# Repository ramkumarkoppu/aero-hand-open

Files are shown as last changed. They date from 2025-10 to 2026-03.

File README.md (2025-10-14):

# License

- Software (firmware, SDK, and control code) is licensed under the [Apache License 2.0](https://www.apache.org/licenses/LICENSE-2.0).
- Hardware (mechanical design, CAD models, and assembly files) is licensed under the [Creative Commons Attribution-NonCommercial-ShareAlike 4.0 International License (CC BY-NC-SA 4.0)](https://creativecommons.org/licenses/by-nc-sa/4.0/).
  
© 2025 TetherIA Inc. All rights reserved.

Aero Hand Overview

Aero Hand Open is an open-source, tendon-driven robotic hand designed and developed by TetherIA. The project aims to make dexterous manipulation research more accessible by providing a fully documented, modular, and affordable platform that can be reproduced with standard 3D printing and off-the-shelf electronic components. 

Unlike many existing robotic hands that rely on expensive proprietary actuators or complex mechanical assemblies, Aero Hand Open focuses on simplicity, reliability, and transparency. Each joint is optimized for mechanical efficiency by using tendon actuation, enabling smooth and natural motion while keeping the overall design lightweight and compact. The system integrates open-source firmware (ESP32-based) and control software compatible with ROS2, allowing seamless integration into research and educational environments. 

This repository serves as a complete open hardware and software reference for developers, students, and robotics enthusiasts.

# Aero Hand Open features:
- 7 DoFs robotic hand with 5 fingers (15 joints in total)
- Tendon-driven architecture for smooth and natural motion
- Fully 3D-printed structure, modular and easy to assemble
- Lightweight design — **<400 g**
- Affordable — complete kit for **$314 USD**
- Open-source hardware and firmware
- Independent Python SDK, and compatible with ESP32 and ROS2 systems

# Overview:

Overview1

Overview1

Overview1

Overview1

Overview1

Overview1

Overview1

# Table of Contents:
- Resources
  - Bill of Materials (BOM)
  - CAD Files and 3D Models
  - Assembly Guide
  - SDK
  - Teleoperation
- Disclaimer
- Project Updates & Community
  - Updates History
  - FAQ
  - Contact

# Resources
## Bill of Materials (BOM)
The complete list of components required to build Aero Hand Open can be found here:

 👉 Aero Hand Open – Bill of Materials

This document includes all mechanical, electronic, and printed parts — such as motors, tendons, bearings, fasteners, and 3D-printed components.

Each item is listed with its part number, vendor, quantity, and estimated cost to help you easily source or substitute parts.

CAD Files and 3D Models
All CAD and 3D model files of Aero Hand Open are available in the directory.

You can find both STEP and STL files for modification and direct 3D printing.

> CAD Files Notes:
> The absolute origin of the full assembly is at the MCP joint of middle finger

For quick setup, we also provide a “One-Click Print Pack”, which contains all parts with pre-oriented build angles optimized for print strength, surface quality, and minimal support usage.

Simply load the files into your slicer and start printing — no additional rotation or manual adjustment is required.

Printing Notes:
- Suggested Printer: Bambau Lab X1C/P1S
- Recommended material: PLA (for stiffness and dimensional accuracy)
- Suggested layer height: 0.2 mm (Nozzle Diameter 0.4mm)
- Support: Autogenerate is fine
- The hand design is fully modular — individual fingers can be printed and replaced independently
- Other information can be found in Assembly Documents

An online Onshape model is also available for quick viewing and part reference:

 👉 Aero Hand Open – Onshape Document

## Assembly Guide
The step-by-step assembly instructions for Aero Hand Open are provided in the following document:

 👉 Aero Hand Open – Assembly Guide (PDF)

This guide covers the entire build process, from mounting the actuators to routing the tendons and connecting the electronics. Each finger module can be assembled independently and attached to the palm afterward, allowing easier maintenance and quick replacement.

## Software SDK
We provide basic introduction and usage here. A detailed introduction to SDK is included in the following folder.

 👉 [`sdk/README.md`](sdk/README.md)

### Installation: 
📦 Install via pip
```bash
pip install aero-hand-sdk
```
     
🧩 Install from source (editable mode)
Clone the repository to your local machine:
```bash
git clone https://github.com/TetherIA/aero-open-sdk.git
```
     
Navigate to the cloned repository directory:
```bash
cd aero-open-sdk
```

Install the package in editable mode:
```bash
pip install -e .
```

### One-Time Setup
When setting up your hand for the first time, our setup GUI helps you configure motor IDs and test motor connections.
After installation, launch the Setup GUI with:
```bash
aero-hand-gui
```

This provides an interactive interface to configure your hand.

### Sequencing Demo
The Sequencing Demo demonstrates how different finger motions can be combined into continuous, pre-defined sequences.

This script enables users to perform complex gestures — such as pinching, opening the palm, or making a peace sign — by automatically coordinating joint movements in a timed sequence.

You can find the example code in the SDK example folder. 

👉 [`sdk/examples/`](sdk/examples)

Once the SDK is installed and the serial port has been configured, you can run any of the example scripts directly using Python as follows:

```bash
python run_sequence.py
```
[🎥 Watch the demo](assets/sequence_square.mp4)

## Teleoperation
The Teleoperation Module enables real-time remote control of Aerobotic hand for intuitive grasping and manipulation experiments.

⚙️ This feature is currently WIP.

# Disclaimer
Aero Hand Open is an open-source research prototype intended for educational and experimental purposes only.

While every effort has been made to ensure build accuracy and functionality, this design has not been validated for prolonged or heavy-duty use.

Users should exercise caution when assembling, operating, or modifying this device. TetherIA Inc. and its contributors shall not be held liable for any personal injury, property damage, or other losses resulting from the use, misuse, or modification of this design. By using this project, you acknowledge and accept full responsibility for any associated risks.

Important Notes:
- 3D-printed parts may exhibit tolerance variations depending on printer and material settings.
- The tendon-driven mechanism requires regular tension adjustment to maintain consistent motion.
- Overloading the joints or applying excessive torque may cause mechanical deformation or servo damage.
- This project is provided as is, without any warranty or guarantee of fitness for a particular purpose.

We encourage the community to share improvements, feedback, and modifications through pull requests or GitHub discussions.

Your contributions will help make Aero Hand Open more reliable and versatile for the entire robotics community.

# Project Updates & Community
## Updates History
- 10/13/2025
  - Product launched on all platforms

## FAQ
Q1: Can I modify and redistribute the Aero Hand Open design?
 A: Yes, as long as it complies with the CC BY-NC-SA 4.0 license (ro Hand Open using data gloves + robotic arms or compatible robotic interfaces. It allows users to map human finger motions to the non-commercial, attribution required, share alike).

Q2: What 3D printer and material do you recommend?
A: Any FDM printer with a ≥200×200 mm bed. PLA works best for strength and dimensional accuracy.

## Contact
For questions, feedback, or collaboration inquiries, please reach out to us through the following channels:

 🛒 Shop: [Aero Hand Open – TetherIA Store](https://shop.tetheria.ai/products/aero-hand-open?variant=51112290320696) 

 📧 Email: support@tetheria.ai

 🌐 Website: [tetheria.ai](http://tetheria.ai)

 🐙 GitHub: [TetherIA](https://github.com/TetherIA)

 💬 Discord: [TetherIA Discord Channel](http://discord.gg/eRAzPMCm)

We welcome discussions, contributions, and new ideas from the community.

If you have improvements to the design, firmware, or control software, feel free to open a Pull Request or start a Discussion on GitHub.

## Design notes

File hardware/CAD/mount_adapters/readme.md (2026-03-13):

This folder contains all the adapters for Aero Hand Open designed for different robotic systems.

For instructions on connecting the adapter(s) with Aero Hand Open, please refer to [Adapter_Assembly_Instructions.pdf](Adapter_Assembly_Instructions.pdf).

## Available Adapters

**piper_arm_adapter.stp** - Designed for the [Piper Arm robotic system](https://global.agilex.ai/products/piper).

**threaded_mount_adapter.stl** - Designed to connect with a tripod mount, as demonstrated in our [previous X post](https://x.com/TetherIA_ai/status/1987711095533113664?s=20).

**135degrees_adapter.stl** - A special adapter for the Piper robot arm that provides an optimal grasping angle. See [reference image](assets/135degrees_adapter.png).

**G1_Open_Unitree_Converter.stl** - adapter for [unitree G1 robot](https://www.unitree.com/g1)

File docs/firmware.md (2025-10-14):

# Firmware

This guide covers architecture, build options, and a detailed communication protocol specification used by the **ESP32‑S3 (Seeed Studio XIAO ESP32S3)** to drive **Feetech HLS3606M servos**.

---

## 🧭 Overview

The firmware exposes a compact **fixed 16‑byte binary serial protocol** for commanding seven actuators (thumb & fingers) and for querying telemetry (position, velocity, current, temperature). It also implements **homing**, **set-id**, **persistent trims**, and safety behaviors on‑board, so a host PC can remain simple.

**Channels (7):**

1. Thumb CMC Abduction Actuator
2. Thumb CMC Flexion Actuator
3. Thumb Tendon Actuator
4. Index Finger Actuator 
5. Middle Finger Actuator
6. Ring Finger Actuator
7. Pinky Finger Actuator

---

## 🧰 Hardware & Software Requirements

* **MCU:** Seeed Studio XIAO ESP32‑S3 (8 MB flash recommended)
* **Servos:** Feetech HLS/SC family (e.g., HLS3606M), IDs mapped to 7 actuators
* **Power:** Servo rail 6–9 V with adequate current capacity; USB-C 5 V for MCU. We recommend a stable power supply at 6V for driving the hand capable of delivering upto 10A.
* **Tools:** Arduino IDE **or** PlatformIO

---

## ⚡ Quick Start

1. **Select the hand** (left/right) in `HandConfig.h` or via a build flag (see below).
2. **Build & flash:**
   * **PlatformIO:** choose `seeed_xiao_esp32s3` ➜ **Upload**
   * **Arduino IDE:** open main sketch ➜ set board to **XIAO ESP32S3** ➜ **Upload**
3. **First boot:** open a serial monitor at the configured baud (commonly 921600 or 1 000 000). Verify the board enumerates and servos respond OK if power is connected.

---

## 📁 Repository Layout

```
/firmware
  ├─ firmware_v0.1.0.ino         # Main sketch: init, parser, handlers, tasks
  ├─ HandConfig.h                # LEFT_HAND / RIGHT_HAND selection
  ├─ Homing.h                    # Homing API + ServoData type
  ├─ Homing.cpp                  # Homing implementation + baselines
  └─ libraries/                  # Third‑party libraries as needed
```

---

## 🔁 Build Configuration: Left vs Right Hand

You can switch hands either by editing `HandConfig.h` **or** using build flags.

* **PlatformIO** (`platformio.ini`):

  ```ini
  [env:seeed_xiao_esp32s3]
  platform = espressif32
  board = seeed_xiao_esp32s3
  framework = arduino
  build_flags = -DRIGHT_HAND       ; or -DLEFT_HAND
  ```
* **Arduino IDE:** temporarily uncomment the macro in `HandConfig.h`.

> Tip: Keep a default committed (often `RIGHT_HAND`) and override via CI or local flags when building the opposite hand.
> Note: You can also use the aero-hand-gui to upload a bin file directly onto the ESP32S3 without using any of this software.

---

## 🔌 Communication Protocol

The protocol is **always 16 bytes** per frame, both **to** and **from** the device. Payload words are **little‑endian**.

### Frame Format

| Bytes | Field | Description |
| ----: | --- | --- |
| 0 | **OPCODE**  | Command / request code |
| 1 | **FILLER**  | Always `0x00` (reserved) |
| 2..15 | **PAYLOAD** | 14‑byte payload; semantics depend on opcode |

> **ACK/Responses** also use the same 16‑byte frame shape; byte 0 contains the response opcode, byte 1 is `0x00`.

### Opcode Reference

> The table below is the canonical mapping used by this firmware version.

| Opcode | Name | Direction | Payload (PC→Device unless noted)  | Notes |
| :----: | --- | :---: | --- | --- |
| `0x01` | **HOMING** | PC→Dev  | none (payload = zeros) | Runs full homing & calibration; blocks other commands until complete; returns an ACK. |
| `0x02` | **SET_ID** | PC→Dev  | `u16 new_id`, `u16 current_limit` | Scans bus for the single attached servo, sets its ID and current limit; returns an ACK with old/new ID and limit. |
| `0x03` | **TRIM** | PC→Dev  | `u16 channel`, `s16 degrees_off`  | Adjusts stored **extend_count** for a channel; persists in NVS; returns an ACK with the resulting extend count. |
| `0x11` | **CTRL_POS** | PC→Dev  | 7×`u16` (ch0..ch6) | Position write for all channels. 0..65535 spans each channel’s **extend ↔ grasp**. No ACK (fire‑and‑go). |
| `0x12` | **CTRL_TOR** | PC→Dev  | TBD | Reserved/To‑be‑implemented torque/effort mode. |
| `0x22` | **GET_POS**  | PC→Dev  | none | Device replies with 7×`u16` raw positions. |
| `0x23` | **GET_VEL**  | PC→Dev  | none | Device replies with 7×`u16` velocities. |
| `0x24` | **GET_CURR** | PC→Dev  | none | Device replies with 7×`u16` currents. |
| `0x25` | **GET_TEMP** | PC→Dev  | none | Device replies with 7×`u16` temperatures. |

#### Position Mapping (CTRL_POS)

For each channel *i*, the firmware maps host value `u16[i]∈[0,65535]` linearly to the servo’s raw count using the per‑channel `extend_count` (open) and `grasp_count` (closed), clamped to `[0,4095]`. Direction is handled via `servo_direction`.

#### Example Sequences

* **Homing**
  PC → Dev: `[0x01, 0x00, 14×0x00]`
  Dev homes all servos → Dev → PC: `[0x01, 0x00, 14×0x00]`

* **Trim channel 3 by −100°**
  PC → Dev: `[0x03, 0x00, 0x03,0x00, 0x9C,0xFF, 10×0x00]`
  Dev updates extend count & saves to NVS → Dev → PC: `[0x03, 0x00, 0x03,0x00, ext_lo,ext_hi, rest 0]`

> **Framing robustness:** Unrecognized opcodes are consumed/ignored to maintain alignment; malformed frames are dropped.

---

## 🧱 Firmware Architecture

### Data Structures

```c++
struct ServoData {              // one per channel
  uint16_t grasp_count;         // closed endpoint (0..4095)
  uint16_t extend_count;        // open endpoint  (0..4095)
  int8_t   servo_direction;     // +1 or −1
};
```

* **Baselines:** compile‑time constants for LEFT and RIGHT hands (7 entries each). A runtime working copy `sd[7]` is refreshed from the baseline (e.g., at boot or before homing).

### Homing Module

* `HOMING_start()` — runs the homing routine for all servos.
* `HOMING_isBusy()` — returns `true` while homing is in progress.
* `resetSdToBaseline()` — copies the correct baseline values into `sd[7]`.

### Concurrency & I/O

* **Bus locking:** all sync read/write operations acquire a semaphore (e.g., `gBusMux`) to prevent collisions.
* **Persistence:** trims (extend counts) are stored in **NVS** so they survive reboots; a full **HOMING** reset returns to baseline.
* **Telemetry:** batched `SyncRead` used for GET_*; CSV printing (if enabled) multiplexed through a single serial writer.

---

## 🧰 Homing Behavior

1. Load the appropriate baseline via `resetSdToBaseline()`.
2. For each servo, drive slowly toward a mechanical stop while monitoring current to detect contact.
3. Calibrate the offset at contact, back‑off/settle, then move to a consistent **extend** posture.

**Notes:** Homing may take around a minute or two overall since each servo is given a timeout of 25s to find a hard mechanical stop in a given direction. During homing, other commands are ignored (buffer on the host if needed), So it will wait for an ACK for a given time period.

---

## 🧩 Extending the Firmware (Add a New Command)

Follow this pattern to add features like LED blink, torque enable, or special saves.

**Step 1 — Define a new opcode**

```c++
static const uint8_t OP_BLINK = 0x42;   // choose an unused byte
```

**Step 2 — Implement a small handler**

```c++
static void handleBlink(uint8_t count) {
  for (uint8_t i = 0; i < count; ++i) {
    digitalWrite(LED_BUILTIN, HIGH); delay(80);
    digitalWrite(LED_BUILTIN, LOW);  delay(80);
  }
}
```

**Step 3 — Wire it into the parser**

```c++
case OP_BLINK: {
  uint8_t count = payload[0];   // interpret first payload byte
  handleBlink(count);
  break;
}
```

**Step 4 — (Optional) ACK**
Return a 16‑byte response if the host should be notified of completion or status.

**Step 5 — Update host tools**
Extend your Python SDK/GUI (e.g., `aero_hand.py`) to emit and consume the new opcode.

---

## 🔐 Safety & Best Practices

* Start with conservative speeds/torque when testing.
* Ensure the servo supply can deliver peak current without large drops.
* Avoid high‑rate position writes during homing.
* Use `HOMING` to re‑establish known geometry if trims become inconsistent.
* Always check power if the servos are not moving.

---

## 🧯 Troubleshooting

* **Wrong hand geometry:** Verify build flag (`-DLEFT_HAND` vs `-DRIGHT_HAND`).
* **Servos move opposite:** Check `servo_direction` or swap extend/grasp counts. We recommend not to change the servo_direction , extend_count can be changed by Trim Servo.
* **Homing stalls:** Inspect current limits/timeouts; verify mechanics move freely.
* **No serial activity:** Confirm COM port/baud and that frames are exactly 16 bytes with valid opcodes.

---

## 📄 License

This project is licensed under **Apache License‑2.0** 

---
## 🤝 Contribution

We welcome community contributions!

If you would like to improve the [Firmware](https://github.com/TetherIA/aero-open-firmware) or add new features:

1. Fork and create a feature branch.
2. Add or modify opcodes and handlers as described in Section 9.
3. Include brief unit/bench tests where possible.
4. Commit your changes with clear messages.
5. Push your branch to your fork.
6. Open a PR with a summary and scope of changes.

---

## 🤝 Support & Contact

* Open a GitHub Issue on the project repository
* Email: **[contact@tetheria.ai](mailto:contact@tetheria.ai)**

<div align="center">
  <br/>
    <b>Happy building!</b><br/>
    Try something new, Break things safely, Share what you learn.<br/>
    If this helps, please ⭐ the repo and share it with others!<br/>
  <br/><br/>
  Built with ❤️ by TetherIA.ai
</div>

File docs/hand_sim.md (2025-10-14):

# Sim and RL

The **TetherIA Aero Hand Open** features a physically accurate **tendon-driven actuation system** that emulates real cable mechanics, allowing control and observation directly in **tendon space**. This design provides a faithful bridge between simulation and real-world deployment.

The hand can be simulated across multiple physics platforms. Currently, it supports the **[MuJoCo simulator](https://mujoco.org/)**, where it is fully integrated into **[MuJoCo Playground](https://github.com/google-deepmind/mujoco_playground)** for seamless visualization, training, and evaluation of tendon-space control policies. Support for additional simulation platforms is currently in progress.

- **Hand Model:** [MuJoCo Menagerie – TetherIA Aero Hand Open](https://github.com/TetherIA/mujoco_menagerie/tree/main/tetheria_aero_hand_open)  
- **Training Tools:** [MuJoCo Playground](https://github.com/TetherIA/mujoco_playground_pr)

---

## 🚀 Quick Start

If you’d like to **train your own policy**, follow these steps:

1. Install **MuJoCo Playground** following the [installation guide](https://github.com/TetherIA/mujoco_playground_pr/blob/main/README.md).  
2. Try the built-in **Z-axis rotation environment** for a quick demo, or create your own custom task following [this example](https://github.com/TetherIA/mujoco_playground_pr/blob/main/mujoco_playground/_src/manipulation/aero_hand/rotate_z.py).  
3. Launch training with:

```bash
python learning/train_jax_ppo.py --env_name AeroCubeRotateZAxis
```
You can replace `AeroCubeRotateZAxis` with the name of your own environment. After training, a rollout video will be saved as `rollout0.mp4`.

If you'd like to explore TetherIA Aero Hand Open within the MuJoCo simulator, follow these steps:

1. Follow the [official MuJoCo installation guide](https://mujoco.readthedocs.io/en/latest/programming/#getting-started).
2. The hand model is hosted under our fork of the MuJoCo Menagerie:
   ```bash
      git clone git@github.com:TetherIA/mujoco_menagerie.git
   ```
3. Navigate to the hand’s directory and open the simulation scene:
   ```bash
      cd mujoco_menagerie/tetheria_aero_hand_open
      simulate scene_right.xml
   ```

**Main features include:**
- Physically consistent tendon routing and pulley mechanics.  
- Full tendon-space control and observation interface.  
- JAX-based PPO training integrated with MuJoCo Playground.  

An overview of the hand is shown below:

| Rock | Paper | Scissor |
|---|---|---|

---

## 1. TetherIA Aero Hand Model

### 1.1 Modeling

The simulation model is derived from URDF models, accurately representing the real mechanical structure. The simulation reproduces the cable actuation through three essential components:

#### 1.1.1 Tendon Drives
Spatial tendons drive the fingers and thumb, following the same routing paths as the real hand.

#### 1.1.2 Springs
Modeled as tendon elements, springs generate restoring forces for finger extension, mirroring the real mechanical springs.

#### 1.1.3 Pulleys
Cylindrical pulleys guide cables and springs to ensure accurate routing and consistent actuation behavior.

| Front view | Close-up of index |
|---|---|
| skeleton | index |

---

### 1.2 Parameters

#### 1.2.1 Mechanical Parameters
- **Joint limits, mass, and inertia:** directly taken from the URDF for physical fidelity.  
- **Pulley placement:** matches the real hand’s geometry, ensuring correct cable and spring routing.  
- **Validation:** the simulated tendon range (0.0459454 m) closely matches the real hand (0.04553 m) without manual adjustment.

#### 1.2.2 Tendon and Spring Specifications
- **Tendon properties:** identical to the real system.  
- **Spring properties:** match hardware specifications, except for the DIP spring—adjusted slightly for more realistic motion.

#### 1.2.3 Control Parameters
All remaining control parameters are fine-tuned to ensure consistent dynamics between simulation and hardware, including:
- Joint damping values  
- Actuator gains  
- Joint-specific damping coefficients. 

---

## 2. Training a Tendon-Space Policy

We introduce a **Z-axis rotation task** for the **TetherIA Aero Hand Open**, optimized using the following reward function:

reward = 1.0 × angular velocity - 1.0 × action rate + termination (-100.0)

The optimization variables include **tendon lengths** and the **thumb abduction joint**, both corresponding to the real actuation system. This design ensures that the same control and sensing channels can be directly applied in **sim-to-real deployment**.

To train the policy:

```bash
python learning/train_jax_ppo.py --env_name AeroCubeRotateZAxis
```

While training results vary slightly due to stochasticity, runs consistently **converge toward a positive total reward**. Below are example reward curves obtained using PPO:

**Overall Reward**
overall

**Angular Velocity Reward**
reward_angvel

**Action-Rate Penalty**
penalty_action_rate

**Termination Penalty**
penalty_termination

---

## 3. Running a Pretrained Policy

This example builds upon **[MuJoCo Playground](https://github.com/google-deepmind/mujoco_playground)** as an educational platform. We are actively working to merge **[our implementation](https://github.com/TetherIA/mujoco_playground_pr)** into the official repository.

To test a trained policy:
```bash
python learning/train_jax_ppo.py
--env_name AeroCubeRotateZAxis
--play_only
--load_checkpoint_path path/to/checkpoints
```

This will:
- Load the trained PPO policy  
- Run rollouts in simulation  
- Visualize the manipulation behavior

| Seed 0 | Seed 1 | Seed 14 |
|---|---|---|
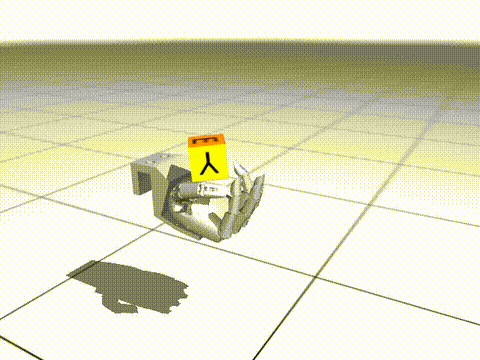
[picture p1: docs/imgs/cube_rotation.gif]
seed0
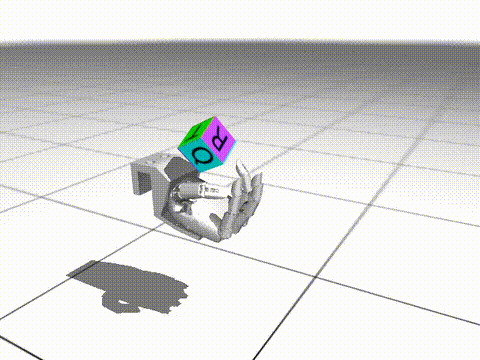
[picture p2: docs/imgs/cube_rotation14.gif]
seed14
|  | seed1 |  |

**Sim-to-Real Deployment on the TetherIA Aero Hand Open**

Z-Axis Rotation Demo

*Note: The finger markers are for visualization only and are **not** used for control.*

---

## 🧩 Acknowledgements

Dependency:  
- [**MuJoCo Playground**](https://github.com/google-deepmind/mujoco_playground).

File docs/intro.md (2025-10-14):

# Aero Hand Open

**Aero Hand Open** is a tendon-driven, under-actuated dexterous robotic hand built for research in manipulation, reinforcement learning, and embodied AI.  
It is designed for reproducibility, transparency, and ease of integration across hardware, firmware, and software layers.

---

## Hardware Overview

The hand adopts a **tendon-driven actuation architecture**, where each motor drives multiple joints through cable routing.  
This approach achieves high dexterity with fewer actuators, resulting in a lightweight and compliant design.

**Key characteristics:**
- 15 Degrees of Freedom (7 active, 8 passive)
- 3 active DoFs for the thumb, enabling real dexterity
- One-motor-per-finger tendon actuation
- Passive 1:1 coupling between DIP and PIP joints
- Adaptive coupling at MCP joint for compliant contact behavior
- Compact servo actuator modules with integrated encoders
- Modular 3D-printable mechanical components
- 6 V DC power input and USB communication
- Fully open-source CAD and PCB design

All mechanical and electrical design files are available in the [`aero-open-hardware`](https://github.com/TetherIA/aero-open-hardware) repository.

---

## Firmware and Control

The onboard controller runs custom firmware supporting:
- Position, velocity, and torque control modes
- High-frequency communication over USB
- Real-time command streaming via ROS 2 and Python SDK
- Built-in calibration and diagnostics utilities

Firmware source code is hosted in [`aero-open-firmware`](https://github.com/TetherIA/aero-open-firmware).

---

## SDK and ROS 2 Integration

Developers can interface with the hand through:
- A **Python SDK** for joint, tendon, and sensor interfaces
- **ROS 2 packages** exposing scripting, teleoperation, and logging
- Example nodes for control, data collection, and policy playback

Software API is maintained in [`aero-open-sdk`](https://github.com/TetherIA/aero-open-sdk).

---

## Simulation and Learning

Aero Hand Open is fully supported in **MuJoCo** with upcoming Issac Sim support, with tendon-level actuation and observation.  
It integrates with popular RL and imitation learning frameworks, including **MuJoCo Playground** and **LeRobot** (coming soon), enabling a consistent sim-to-real workflow.

Use simulation to train control policies, benchmark algorithms, and prototype manipulation tasks before deployment on real hardware.

---

## Repository Structure

| Component | Repository | Description |
|---|---|---|
| Hardware | [`aero-open-hardware`](https://github.com/TetherIA/aero-open-hardware) | CAD models, assembly, and tendon routing |
| Firmware | [`aero-open-firmware`](https://github.com/TetherIA/aero-open-firmware) | Embedded control software |
| SDK / GUI | [`aero-open-sdk`](https://github.com/TetherIA/aero-open-sdk) | Python SDK and GUI |
| Documentation | [`aero-open-docs`](https://github.com/TetherIA/aero-open-docs) | Documentation source |
| Monorepo | [`aero-hand-open`](https://github.com/TetherIA/aero-hand-open) | Consolidated repository for community contributions |

---

## Getting Started

- [Build and assemble the hand →](./assembly.md)  
- [Flash and verify firmware →](./firmware.md)  
- [Connect via ROS 2 or Python SDK →](./sdk.md)
- [Getting Started with GUI of SDK →](./getting_started.md)  
- [Run simulation in MuJoCo →](./hand_sim.md)

---

## License

All components of Aero Hand Open are released under permissive open-source licenses.  
Please refer to individual repositories for license details.

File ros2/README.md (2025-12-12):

<p align="center">
  Aero Hand Open by TetherIA
  <br/><br/>
</p>
 
<div align="center">




</div>

<h2 align="center">
  <p>Aero Hand ROS2 — ROS2 package for for TetherIA's Robotic Hand</p>
</h2>

<div align="center">
  Aero Hand Demo Aero Hand in action
  <p><strong>Aero Hand Open</strong> is a 7-DoF tendon-driven robotic hand for dexterous manipulation and research.</p>
</div>

---

## ⚙️ Installation

We currently have tested the ROS2 package on **Ubuntu 22.04** with **ROS2 Humble Hawksbill**.

### Prerequisites

Before installing this package, ensure you have:
- ROS2 Humble installed. Follow the official guide [here](https://docs.ros.org/en/humble/Installation/Ubuntu-Install-Debians.html).
- `colcon` build tool installed. You can install it via:
  ```bash
  sudo apt install python3-colcon-common-extensions
  ```
- The [Aero Hand SDK](https://github.com/TetherIA/aero-hand-open/tree/main/sdk) installed, follow the installation instructions in its README.

### Installation Steps

To install the `aero-open-ros2` package, follow these steps:

1. Clone the repository to your local machine:
   ```bash
   git clone https://github.com/TetherIA/aero-open-ros2.git
   ```

2. Navigate to the cloned repository directory:
   ```bash
   cd aero-open-ros2
   ```

3. Build the packages with colcon:
   ```bash
   colcon build
   ```

4. Source the workspace:
   ```bash
   source install/setup.bash
   ```

---

## 🚀 Next Steps

Take a look at the [Aero Hand Open README](src/aero_hand_open/README.md) next to get started with using the Aero Hand Open ROS2 package.

## 🧰 Troubleshooting

Coming soon — common setup and runtime issues will be documented here.

## 💬 Support

If you encounter issues or have feature requests:
- Open a [GitHub Issue](https://github.com/TetherIA/aero-open-ros2/issues)
- Contact us at **support@tetheria.ai**

---

## 🤝 Contribution

We welcome community contributions!

If you'd like to improve the SDK, fix bugs, or add new features:

1. Fork this repository.
2. Create a new branch for your changes.
    ```bash
    git checkout -b feature/your-feature-name
    ```

3. Commit your changes with clear messages.

4. Push your branch to your fork.

5. Open a Pull Request (PR) describing your updates.

---

## ⚖️ License

This project is licensed under the **Apache License 2.0**.

<div align="center">
If you find this project useful, please give it a star! ⭐

Built with ❤️ by TetherIA.ai
</div>

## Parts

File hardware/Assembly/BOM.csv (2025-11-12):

 | P/N | Name | Material | Qty per Hand | Volume (mm^3) | Total Cost per Hand | Link | Alternative | Notes
3D Printed | 1 | Finger Base | PLA | 4 | 975 | 0.024362813 | Bambu Lab |  | 3DP parts have been designed for PLA printed on a Bambu X1C with a 0.4mm nozzle. Tolerances may need to change if printing with different materials/nozzles/printers.
 | 2 | Finger MCP | PLA | 4 | 606 | 0.015142425
 | 3 | Finger Proximal | PLA | 4 | 5776 | 0.1443278
 | 4 | Finger Medial | PLA | 4 | 2644 | 0.06606695
 | 5 | Finger Distal | PLA | 4 | 1547 | 0.038655663
 | 6 | Cable Spool | PLA | 6 | 735 | 0.018365813
 | 7 | Thumb Abduction Upper Servo Disk | PLA | 1 | 786 | 0.019640175
 | 8 | Thumb Abduction Lower Servo Disk | PLA | 1 | 1366 | 0.034132925
 | 9 | Thumb Abduction Linkage Bar | PLA | 1 | 334 | 0.008345825
 | 10 | Thumb CMC Base | PLA | 1 | 5548 | 0.13863065
 | 11 | Thumb MCP | PLA | 1 | 11204 | 0.27995995
 | 12 | Thumb Proximal | PLA | 1 | 6926 | 0.173063425
 | 13 | Thumb Distal | PLA | 1 | 3912 | 0.0977511
 | 14 | Servo Frame | PLA | 1 | 15055 | 0.376186813
 | 15 | Palm Front Frame | PLA | 1 | 18734 | 0.468115825
 | 16 | Palm Rear Frame | PLA | 1 | 106254 | 2.655021825
 | 17 | Silicone molds Top | PLA | 1 | 39531 | 0.987780863
 | 18 | Silicone molds Bottom | PLA | 1 | 51643 | 1.290429463
Casting | 19 | Finger Distal Pad | 00-30 Silicone | 4 | 1322 | 0.02754653 | https://www.amazon.com/Ecoflex-00-30-Super-Platinum-Silicone/dp/B00CA5VY3U |  | We recomend using silicone pads to maximize compliance and grip however we also provide files for tpu to replace the foam. The hand functionality will be slightly lowered with the use of TPU.
 | 20 | Finger Proximal Pad | 00-31 Silicone | 4 | 1123 | 0.023399965
 | 21 | Thumb Distal Pad | 00-32 Silicone | 1 | 2998 | 0.062469363
 | 22 | Palm Frame Pad | 00-33 Silicone | 1 | 12180 | 0.253794808
 |  | Name | Material | Qty per Hand | Unit Cost | Total Cost Per Hand | Link | Alternative | Notes
Purchased Components | 23 | Finger Distal/Medial and Thumb Proximal/Distal Return Spring (PIP) | Music Wire | 5 | 5.27 | 26.35 | https://www.thespringstore.com/pe020-140-33500-mw-0840-mh-n-in.html
 | 24 | Finger Proximal/MCP Return Spring (MP) | Music Wire | 4 | 3.27 | 13.08 | https://www.centuryspring.com/shop/m-35cs
 | 25 | Thumb CMC/MCP Return Spring (CMC) | Music Wire | 1 | 4.93 | 4.93 | https://www.thespringstore.com/pe023-172-11218-mw-0470-mh-n-in.html
 | 26 | Finger Pull Cable | Kevlar/Vectran | 3 | 6.29 | 6.29 | https://www.amazon.com/9KM-DWLIFE-Strength-Retardant-Ridgeline/dp/B0B1WKH21R?s=sporting-goods | https://twinline-usa.com/collections/vectran-per-pound/products/braided-vectran-125-spools | The hand is designed to use this specific vectran however kevlar can be used
 | 27 | Pinky Pull Cable | Kevlar/Vectran | 1
 | 28 | Finger Coupling Cable | Kevlar/Vectran | 4
 | 29 | Thumb CMC Flex Cable | Kevlar/Vectran | 1
 | 30 | Thumb Pull Cable | Kevlar/Vectran | 1
 | 31 | Thumb Coupling Cable | Kevlar/Vectran | 1
 | 32 | 2x5x2.5 bearing | Steel | 23 | 0.5216 | 11.9968 | https://www.amazon.com/Yodaoke-MR52ZZ-2x5x2-5mm-Miniature-Bearings/dp/B08L7NTVK7 | https://www.amazon.com/dp/B08L7NTVK7?ref=fed_asin_title | Pins and bearings can vary depending on the supplier. The biggest issue will be fitting pins through the bearings. We recommend buying undersized pins to ensure the pins maintain a slip fit with the bearings. We spec a cheap bearing from amazon that works, however if there are fitment issues we recomend using the bearings from misumi
 | 33 | 1x10 Pin | Steel | 16 | 0.158 | 2.528 | https://www.mcmaster.com/91585A091/ | https://us.misumi-ec.com/vona2/detail/110300255260/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
 | 34 | obsolete (2x10 Pin) | Steel | 0 | 0.159 | 0 | https://www.mcmaster.com/91585A221/ | https://us.misumi-ec.com/vona2/detail/110300255260/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
 | 35 | 2x14 Pin | Steel | 12 | 0.194 | 2.328 | https://www.mcmaster.com/91585A226/ | https://us.misumi-ec.com/vona2/detail/221000746912/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
 | 36 | 2x20 Pin | Steel | 2 | 1 | 2 | https://www.mcmaster.com/91585A240/ | https://us.misumi-ec.com/vona2/detail/110300255260/?HissuCode=MSCSS2-20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
 | 37 | UNDERSIZED 2x10 Pin | Steel | 19 | 0.156 | 2.964 | https://www.mcmaster.com/97049A104/ | https://us.misumi-ec.com/vona2/detail/110302390530/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
 | 38 | UNDERSIZED 2x20 Pin | Steel | 1 | 1.52 | 1.52 | https://us.misumi-ec.com/vona2/detail/110302390530/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 | https://us.misumi-ec.com/vona2/detail/110302390530/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
 | 39 | UNDERSIZED 2x30 Pin | Steel | 1 | 1.34 | 1.34 | https://us.misumi-ec.com/vona2/detail/110302390530/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 | https://us.misumi-ec.com/vona2/detail/110302390530/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
 | 40 | M2x6 Flanged Torx Self Tapping Screw | Steel | 25 | 0.403 | 10.075 | https://www.mcmaster.com/catalog/131/3434/96817A406
 | 41 | M2x10 Countersunk Torx Self Tapping Screw | Steel | 12 | 0.3 | 3.6 | https://www.mcmaster.com/95893A167/
 | 42 | M3x10 Rounded Torx Self Tapping Screw | Steel | 9 | 0.118 | 1.062 | https://www.mcmaster.com/96817A322/
 | 43 | M3x5.7 Heat set insert | Brass | 4 | 0.209 | 0.836 | https://www.mcmaster.com/94459A140/
 | 44 | Feetech HLS3606M Servo Motor | Comes with purchase of servo from Feetech | 7 | 29.83 | 208.81 | https://www.alibaba.com/product-detail/FEETECH-HLS3606M-6V-6Kg-cm-Torque_1601281149843.html
 | 45 | Servo Motor Mount Plate
 | 46 | Servo Motor Spline Screw M2.3x5
 | 47 | Servo Motor Plate Screw M2x4
 | 48 | Connection Board and Cable
 | 49 | TTLinker Mini UART Signal Conversion Board | PCB | 1 | 1.58 | 1.58 | https://www.alibaba.com/product-detail/TTLinker-Mini-UART-Signal-Conversion-Board_60370504430.html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
 | 50 | ESP32-S3 | PCB | 1 | 7.99 | 7.99 | https://www.seeedstudio.com/XIAO-ESP32S3-p-5627.html
 |  | Total |  |  |  | 316.482991
Optional |  | Molex Connector | - | 7 | 0.21 | 1.47 | https://www.digikey.com/en/products/detail/molex/0022035035/403302 |  | For optional soldered breadboard or you can use the Feetech junction boards that come with each servo to daisy chain the servos together and control them or you can buy/make the pcb design we are working on
 |  | Proto Board | - | 1 | 13.5 | 13.5 | https://www.sparkfun.com/sparkfun-snappable-protoboard.html

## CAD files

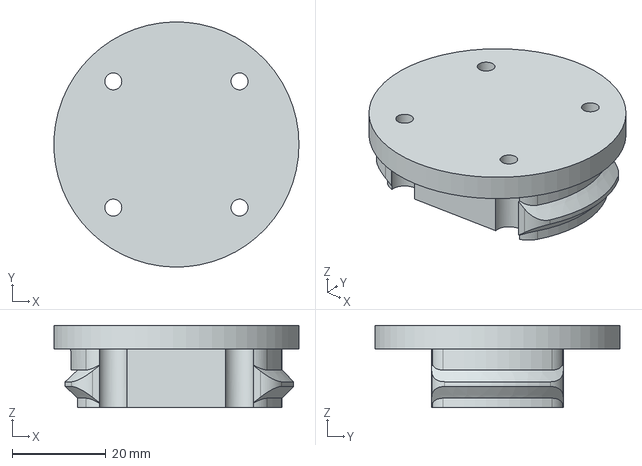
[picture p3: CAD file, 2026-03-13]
hardware/CAD/mount_adapters/G1_Open_Unitree_Converter.stp
52.2 x 52.2 x 17.5 mm

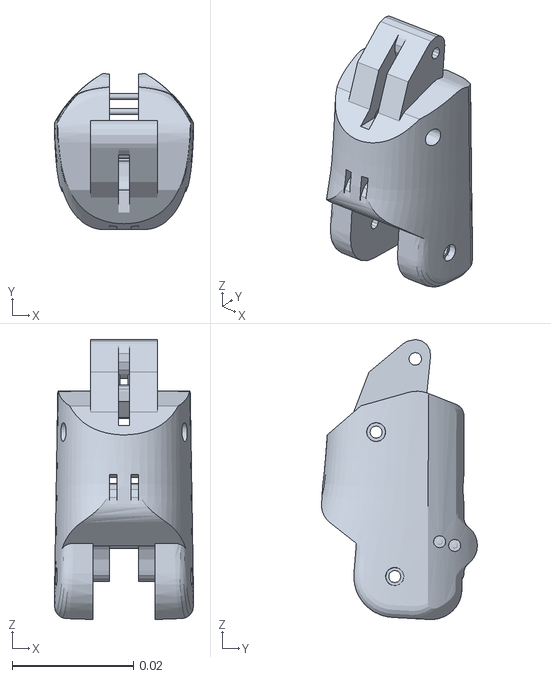
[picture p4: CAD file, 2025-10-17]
ros2/src/aero_hand_open_description/meshes/right_thumb_mcp_link.STL
0.023 x 0.0257 x 0.0461

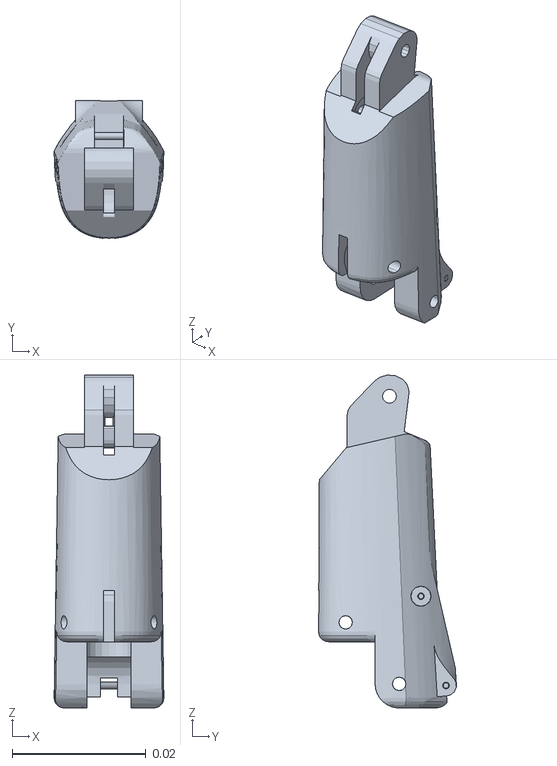
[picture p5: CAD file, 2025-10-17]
ros2/src/aero_hand_open_description/meshes/right_middle_proximal_link.STL
0.0164 x 0.0206 x 0.0498

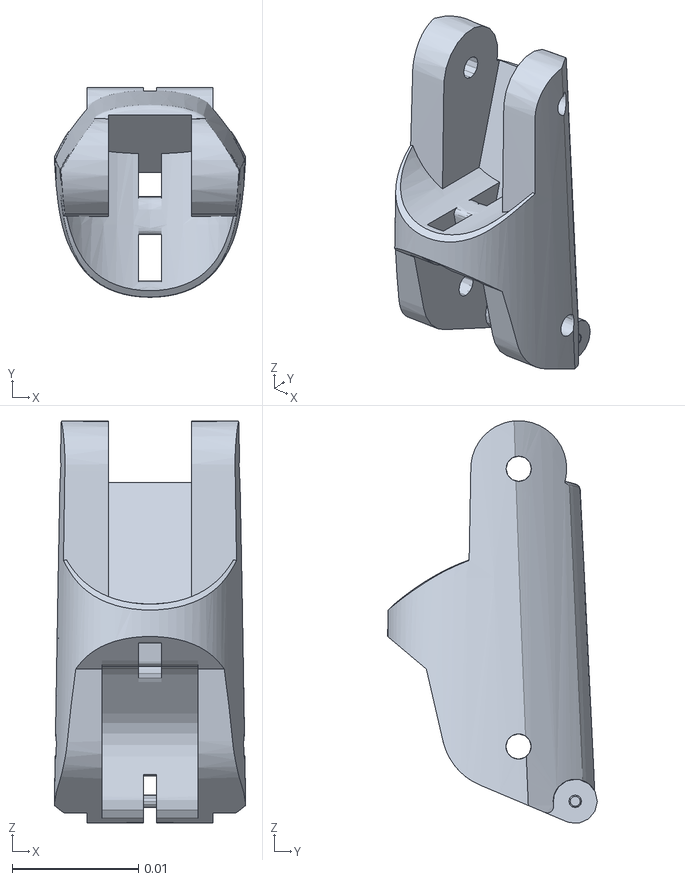
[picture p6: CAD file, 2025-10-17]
ros2/src/aero_hand_open_description/meshes/right_pinky_middle_link.STL
0.0152 x 0.0166 x 0.0318

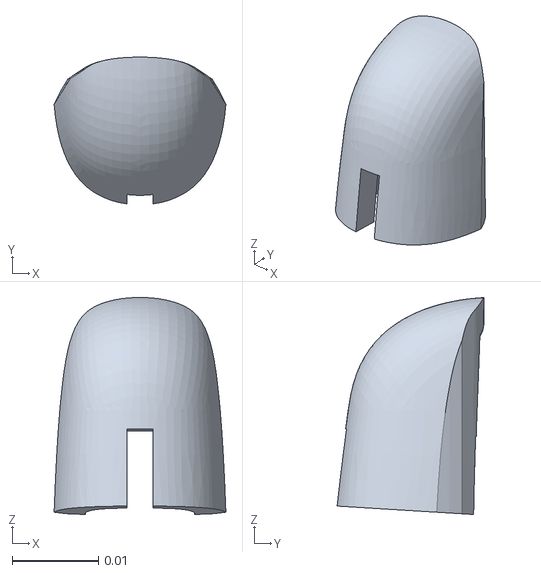
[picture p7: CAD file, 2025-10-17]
ros2/src/aero_hand_open_description/meshes/right_thumb_tip_link.STL
0.0199 x 0.017 x 0.0251

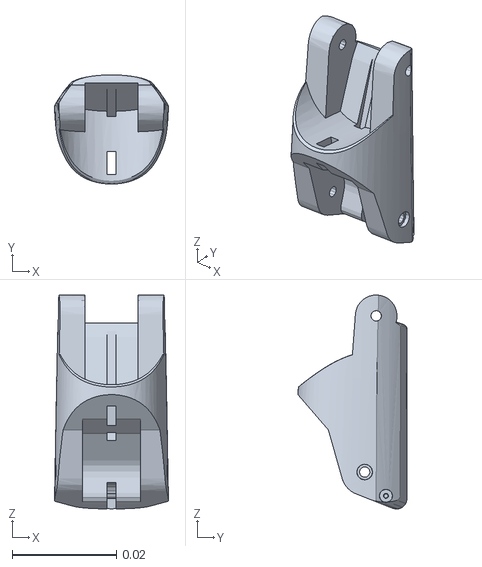
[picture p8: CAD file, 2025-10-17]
ros2/src/aero_hand_open_description/meshes/right_thumb_proximal_link.STL
0.0218 x 0.0209 x 0.041

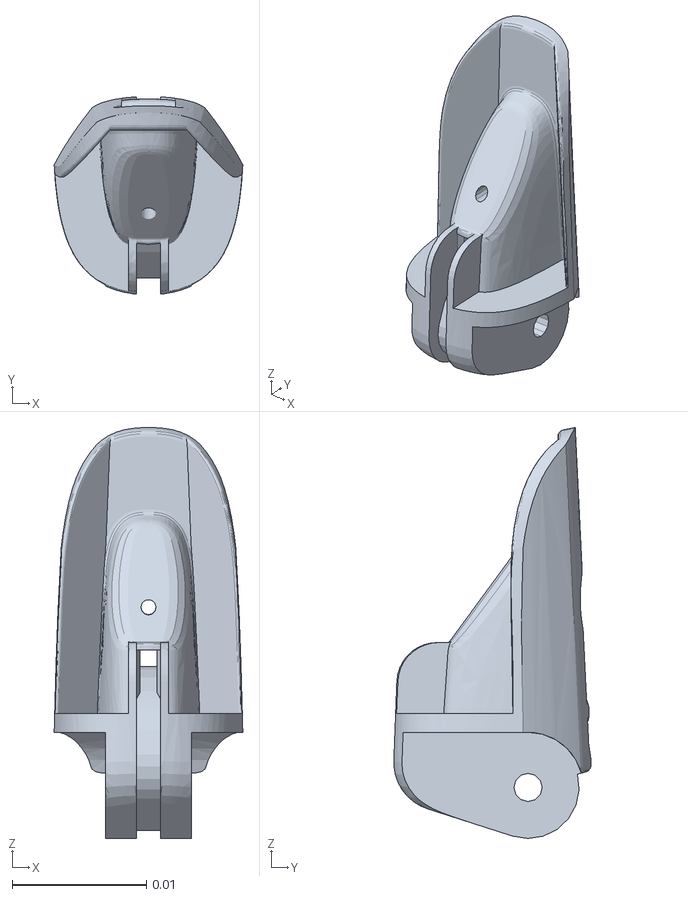
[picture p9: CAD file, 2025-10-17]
ros2/src/aero_hand_open_description/meshes/right_ring_distal_link.STL
0.014 x 0.0147 x 0.0306

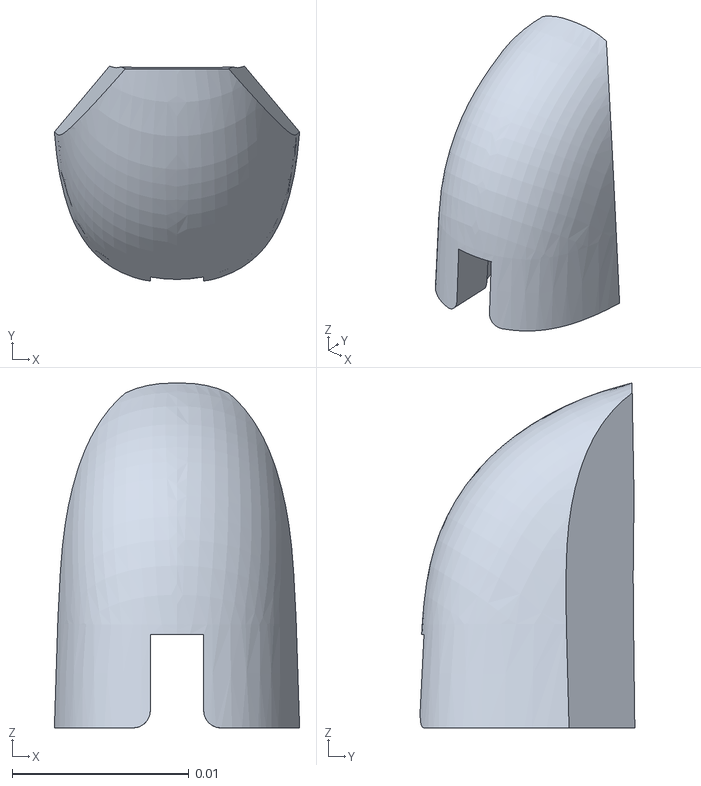
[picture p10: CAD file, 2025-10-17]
ros2/src/aero_hand_open_description/meshes/right_pinky_tip_link.STL
0.0139 x 0.0121 x 0.0195

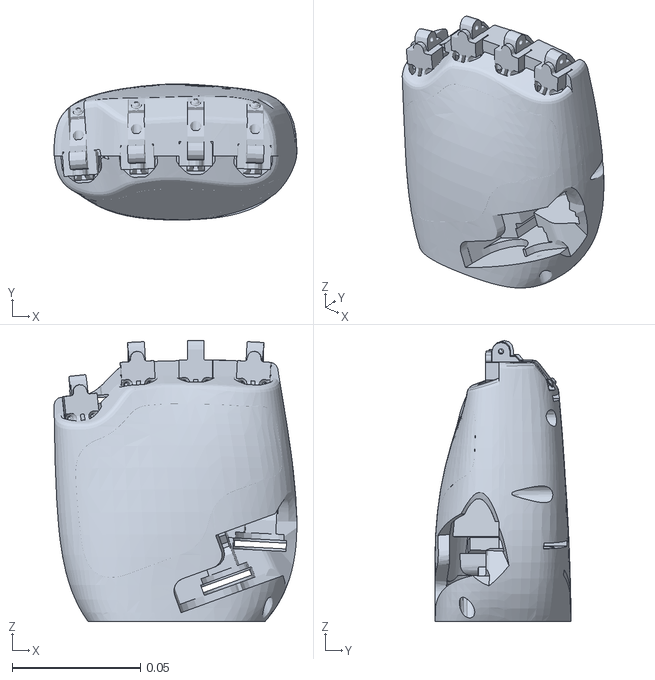
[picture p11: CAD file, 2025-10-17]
ros2/src/aero_hand_open_description/meshes/right_base_link.STL
0.0946 x 0.053 x 0.109

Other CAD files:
ros2/src/aero_hand_open_description/meshes/right_index_proximal_link.STL
ros2/src/aero_hand_open_description/meshes/right_index_middle_link.STL
ros2/src/aero_hand_open_description/meshes/right_pinky_distal_link.STL
ros2/src/aero_hand_open_description/meshes/right_index_tip_link.STL
ros2/src/aero_hand_open_description/meshes/right_ring_tip_link.STL
ros2/src/aero_hand_open_description/meshes/right_ring_middle_link.STL
ros2/src/aero_hand_open_description/meshes/right_middle_middle_link.STL
ros2/src/aero_hand_open_description/meshes/right_middle_tip_link.STL
ros2/src/aero_hand_open_description/meshes/right_middle_distal_link.STL
ros2/src/aero_hand_open_description/meshes/right_index_distal_link.STL
ros2/src/aero_hand_open_description/meshes/right_pinky_proximal_link.STL
ros2/src/aero_hand_open_description/meshes/right_ring_proximal_link.STL
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

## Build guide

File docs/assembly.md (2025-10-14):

# Assembly Instructions

This page contains the complete assembly instructions for the Aero Hand.

## View Instructions

You can view the assembly instructions PDF below, or [download it directly](./Assembly_Instructions.pdf).

<div style={{position: 'relative', width: '100%', height: '800px', border: '1px solid #ccc', borderRadius: '4px', overflow: 'hidden'}}>
  <iframe
    src={require('./Assembly_Instructions.pdf').default}
    style={{width: '100%', height: '100%', border: 'none'}}
    title="Assembly Instructions PDF"
  />
</div>

## Download

If the embedded viewer doesn't work in your browser, you can [download the PDF file here](./Assembly_Instructions.pdf).

---

:::tip
If you have any questions during assembly, please reach out to our community on [Discord](https://discord.gg/eRAzPMCm).
:::

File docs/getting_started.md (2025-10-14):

# First - Time Setup
## 🖥️ GUI — Aero Hand Open Control App

Launch the GUI from a terminal after installation:

```bash
aero-hand-gui
```

> If your system can’t find the command, ensure your Python environment’s scripts directory is on PATH and that the package was installed into the active environment.

<div align="center">
  Screenshot of GUI
</div>

### 🧩 First‑Time Setup: Uploading Firmware

To upload firmware to your Aero Hand device:

1. **Refresh all ports** in the GUI to detect connected devices.
2. If multiple ports are listed, identify the port for your ESP device:
  - On **Windows**, it is usually a **COM** port (e.g., COM3, COM12).
  - On **Linux**, look for `/dev/ttyACM0`, `/dev/ttyACM1`, etc.
3. Select the correct port and press the **Upload Firmware** button.
4. A dialog box will open—navigate to and select the appropriate firmware `.bin` file (`firmware_righthand.bin` or `firmware_lefthand.bin`).
5. The tool will upload the `.bin` file to the device at offset address **0x10000**.
6. On successful upload, you will see a confirmation message in the GUI.

uploading Firmware

#### Notes & Troubleshooting

1. If you encounter errors, first check that you have selected the correct COM port.
2. The tool uses **esptool version 5 or greater**. Older versions may not work, as they use `write_flash` instead of `write-flash`.
3. After flashing, the tool will attempt to reconnect to the ESP automatically (up to 3 attempts). Usually, it connects on the first try. If not, refresh your ports and try again.
4. The firmware is uploaded to offset **0x10000**. Do not use merged or partition `.bin` files, as these may cause errors. Only use the provided bin files from the `aero-open-firmware` repository.

Next step is to set the servo IDs, see the next section below.

### Setting Servo -IDs

1. **Power** the board with the 6V and connect USB.
2. **Connect exactly one servo** to the bus.
3. In the GUI, choose the correct **COM Port**, press **Connect**.
4. Click **Set ID** and assign the servo for the channel you’re wiring:
  * `0 → thumb_abduction_actuator`
  * `1 → thumb_flex_actuator`
  * `2 → thumb_tendon_actuator`
  * `3 → index_finger_actuator`
  * `4 → middle_finger_actuator`
  * `5 → ring_finger_actuator`
  * `6 → pinky_finger_actuator`
5. If the id is successfully set, You will receive an ACK in the RX bar below.
6. If you receive 65535 in oldid,new id and current as ACK , It indicates that the id is not successfully set.
7. After setting up the ID, you can move the responsible slider to make sure whether the actuator is moving or not.
8. Disconnect that servo, plug the next one, and **repeat** until all seven are assigned.

Setting Servo - IDs

### Notes & Troubleshooting

1. Make sure that the board has power and exactly one servo is connected before setting the ID.
2. We recommend setting IDs for all servos in sequence (0–6). Any value apart from 0–6 will not be accepted.
3. For current limit, we recommend keeping it at the maximum (1023) and pressing OK—do not change this value unless necessary.
4. After setting the ID, you will receive the old ID, new ID, and current limit of the servo as confirmation.
5. If you receive 65535 in old ID, new ID, and current limit, this indicates that two or more servos are present and the Set ID mode will not proceed.
6. Once all IDs are Set, We recommend not to use this function once you are playing and training with the hand.

### Trim Servo

When using Trim Servo:
First, you will be asked to enter the servo channel (0–6), which represents the sequence: thumb abduction, thumb flexion, thumb tendon, and the four fingers. Next, enter the degrees offset. We recommend making adjustments in steps of 10–20 degrees, then observe the effect using the sliders. If something unusual happens, you may need to perform the homing procedure again to reset the extend count to the baseline.

#### Left Hand Actuator Table
| Channel | Actuator Name | Extend Count | Grasp Count | Motion (°) | Direction | 
|---|---|---|---|---|---|
| 0 | Thumb Abduction | 2048 | 3186 | 100 | +1 | 
| 1 | Thumb Flexion | 865 | 2048 | 104 | -1 | 
| 2 | Thumb Tendon | 2980 | 0 | 262 | +1 | 
| 3 | Index Finger | 817 | 4095 | 288 | -1 | 
| 4 | Middle Finger | 817 | 4095 | 288 | -1 | 
| 5 | Ring Finger | 817 | 4095 | 288 | -1 |
| 6 | Pinky Finger | 817 | 4095 | 288 | -1 |

#### Right Hand Actuator Table

| Channel | Actuator Name | Extend Count | Grasp Count | Motion (°) | Direction | 
|---|---|---|---|---|---|
| 0 | Thumb Abduction | 2048 | 910 | 100 | -1 |
| 1 | Thumb Flexion | 3231 | 2048 | 104 | +1 |
| 2 | Thumb Tendon | 1115 | 4095 | 262 | -1 | 
| 3 | Index Finger | 3278 | 0 | 288 | +1 | 
| 4 | Middle Finger | 3278 | 0 | 288 | +1 |
| 5 | Ring Finger | 3278 | 0 | 288 | +1 |
| 6 | Pinky Finger | 3278 | 0 | 288 | +1 |

*Motion (°) is calculated as (Grasp Count - Extend Count) / 11.375*

##### Example: Trimming Right Hand Servo Channel 2 by +10 Degrees

Suppose you set +10 degrees trim for the right hand, servo channel 2 (Thumb Tendon Actuator):
- Original Extend Count: 1115
- Grasp Count: 4095
- Each degree corresponds to 11.375 counts.
- So, +10 degrees will update Extend Count to:
  
  1115 + (10 × 11.375) = 1228 (rounded to 1228)

- The new range of motion will be:
  
  4095 - 1228 = 2867 counts

This means the servo will now move through 2867 counts instead of the original 2980 counts which represent 262 degrees of motion and now it will move 252 degrees of total motion only, which will reduce the full range of motion and make it more tight. If you do in the opposite direction , It will increase the motion of servo which will loose the wire and may cause issues. Since , You cannot mofidy the grasp count of the servo, We recommned to go through this table before doing any changes.

Trim Servo

#### Notes & Troubleshooting
1. Do not enter values like 360 or -360 degrees, as this may completely change your control direction—please avoid this.
2. If the servo becomes too tight, try loosening it by entering degrees in the opposite direction to your last adjustment.
3. Use this function only when you want fine control over the servo's range of motion.
4. Disconnect power immediately if any actuator moves to an abrupt position and draws stall current (typically 1.3–1.5A).

### 🎛️ Top Bar Controls

* **Port**: Dropdown of available serial ports.
  Use **Refresh** to re‑scan if you plug/unplug devices.
* **Baud**: Serial speed. Default 921600 is typical for fast streaming and our firmware uses the same baudrate as well.
* **Connect / Disconnect**: Open or close the selected serial port.
* **Rate (Hz)**: How often the GUI streams **CTRL_POS** frames while you move sliders.
  **Recommended:** 50 Hz for smooth motion without saturating USB.

### 🧪 Action Buttons (left→right)

* **Homing** 🏠: Sends opcode `0x01` to run the on‑board homing routine.Any Other Input is ignored while homing is active; wait for ACK under a given timeout of 3minutes.
* **Set ID** 🆔: Guided flow to set a servo’s bus ID. Requires a **single** servo connected; the firmware verifies this before writing.
* **Trim Servo** ✂️: Fine‑tune alignment per channel. Enter **channel (0–6)** and **degrees offset** (±). The firmware adjusts/persists the channel’s `extend_count` in NVS so it survives reboots. Use small steps (±5–10°) and test.
* **Upload Firmware** ⬆️: Flash a `.bin` directly from the GUI. After selection, the board is reset into bootloader, the image is written, and the device restarts.
* **Set to Extend** 🔄: Sends a single **CTRL_POS** frame that sets **all channels to 0.000** (fully open / extend posture). Handy as a “panic open”.
* **GET_POS** 📍: Requests positions. Values are shown normalized **0.000 → 1.000**, computed from each channel’s `extend↔grasp` calibration (host 0..65535).
* **GET_VEL** 💨: Requests velocities of the actuator motions.
* **GET_CURR** 🔌: Requests currents in **mA**, **signed** — the **sign reflects motor direction** relative to the channel’s servo direction (use magnitude to gauge load).
* **GET_TEMP** 🌡️: Requests temperatures (°C) from each servo.
* **GET_ALL** 📦: Convenience burst that triggers **POS + VEL + CURR + TEMP** reads in one go and prints results to the log.

### 🧷 Sliders Panel (Center)

Each row controls a single actuator channel with a **normalized slider**:

* **0.000 → 1.000** maps linearly to the channel’s calibrated **extend ↔ grasp** range in 2 bytes and sent as 14 bytes payload using CTRL_POS Command.
* While you drag, the GUI streams **CTRL_POS** frames at the selected **Rate (Hz)**.
* Two small numeric readouts show the current command and (when polled) the latest normalized feedback.

**Channel map (top→bottom):** `thumb_abduction_actuator`, `thumb_flex_actuator`, `thumb_tendon_actuator`, `index_finger_actuator`, `middle_finger_actuator`, `ring_finger_actuator`, `pinky_finger_actuator`.

### 📟 Status & Logs (Bottom)

* **Status bar** (left): Connection state (e.g., *Disconnected*, *COM12 @ 921600*), last error, and homing/flash progress messages.
* **RX Log**: Text console of responses/telemetry. Useful for debugging, verifying opcodes, and viewing GET_* results.
* **Clear Log**: Clears the RX Log display (does not affect device state).

### 🧰 Tips & Tricks

* **Port not listed?** Click **Refresh**; check drivers, cables, and that no other app is holding the port.
* **Set‑ID fails?** Ensure only one servo is connected and the servo rail is powered.
* **No motion?** Verify you selected the correct hand build (left/right), try **Set to Extend**, then move sliders slowly.
* **Choppy control?** Lower **Rate (Hz)** or close other serial/USB‑heavy apps.

### 🐍 Python Control & Examples

Prefer scripting or automation? Use the Python SDK to send the same 16‑byte frames programmatically and log telemetry.

* Import the high‑level class (e.g., `AeroHand`) and browse **examples** in this repo’s `examples/` folder.
* The GUI and SDK speak the **same protocol**, so your scripts and the app can be used interchangeably during development.

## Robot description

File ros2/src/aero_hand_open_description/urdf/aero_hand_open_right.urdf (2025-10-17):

<?xml version="1.0" encoding="utf-8"?>
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
<robot name="aero_hand_open_right">
  <link name="right_base_link">
    <inertial>
      <origin xyz="0.00109122507694746 0.00334946623951281 0.0489855934276007" rpy="0 0 0" />
      <mass value="0.303576106034272" />
      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
    </inertial>
    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
  </link>
  <link name="right_t_link">
    <inertial>
      <origin xyz="-0.000883525104759189 0.00170407980029484 0.00831028240403424" rpy="0 0 0" />
      <mass value="0.00833536405562315" />
      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
    </inertial>
    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
  </link>
  <joint name="right_thumb_cmc_abd" type="revolute">
    <origin xyz="0.028112 -0.0145 0.025363" rpy="-1.2217 -0.0 -1.57" />
    <parent link="right_base_link" />
    <child link="right_t_link" />
    <axis xyz="0 1 0" />
    <limit lower="0" upper="1.7453" effort="0" velocity="0" />
  </joint>
  <link name="right_thumb_mcp_link">
    <inertial>
      <origin xyz="-1.9848E-07 0.00075445 0.014668" rpy="0 0 0" />
      <mass value="0.008207" />
      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
    </inertial>
    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
  </link>
  <joint name="right_thumb_cmc_flex" type="revolute">
    <origin xyz="-0.003475 0.003808 0.019656" rpy="0.1325 -0.17906 0.26195" />
    <parent link="right_t_link" />
    <child link="right_thumb_mcp_link" />
    <axis xyz="1 0 0" />
    <limit lower="0" upper="0.9599" effort="0" velocity="0" />
  </joint>
  <link name="right_thumb_proximal_link">
    <inertial>
      <origin xyz="7.9121E-09 0.001007 0.011955" rpy="0 0 0" />
      <mass value="0.005471" />
      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
    </inertial>
    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
  </link>
  <joint name="right_thumb_mcp" type="revolute">
    <origin xyz="0 0.0033822 0.035848" rpy="0 0 0" />
    <parent link="right_thumb_mcp_link" />
    <child link="right_thumb_proximal_link" />
    <axis xyz="1 0 0" />
    <limit lower="0" upper="1.5708" effort="0" velocity="0" />
  </joint>
  <link name="right_thumb_distal_link">
    <inertial>
      <origin xyz="-6.4155E-07 -0.0011983 0.010377" rpy="0 0 0" />
      <mass value="0.0032396" />
      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
    </inertial>
    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
  </link>
  <joint name="right_thumb_ip" type="revolute">
    <origin xyz="0 0.002206 0.029919" rpy="0 0 0" />
    <parent link="right_thumb_proximal_link" />
    <child link="right_thumb_distal_link" />
    <axis xyz="1 0 0" />
    <limit lower="0" upper="1.5708" effort="0" velocity="0" />
  </joint>
  <link name="right_thumb_tip_link">
    <inertial>
      <origin xyz="2.2383E-07 -0.010203 -0.013939" rpy="0 0 0" />
      <mass value="0.00086967" />
      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
    </inertial>
    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
  </link>
  <joint name="right_thumb_tip" type="fixed">
    <origin xyz="0 0.0059474 0.031823" rpy="0 0 0" />
    <parent link="right_thumb_distal_link" />
    <child link="right_thumb_tip_link" />
    <axis xyz="0 0 0" />
  </joint>
  <link name="right_index_proximal_link">
    <inertial>
      <origin xyz="4.30529992941076E-08 -0.0024559603959039 0.0191142514901699" rpy="0 0 0" />
      <mass value="0.00720026836301954" />
      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
    </inertial>
    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
  </link>
  <joint name="right_index_mcp_flex" type="revolute">
    <origin xyz="0.030626 -0.0011782 0.10542" rpy="0 0.05236 -0.034907" />
    <parent link="right_base_link" />
    <child link="right_index_proximal_link" />
    <axis xyz="1 0 0" />
    <limit lower="0" upper="1.5708" effort="0" velocity="0" />
  </joint>
  <link name="right_index_middle_link">
    <inertial>
      <origin xyz="-6.47985752902369E-09 -0.000363269614703799 0.00876079008757696" rpy="0 0 0" />
      <mass value="0.00276150356687874" />
      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
    </inertial>
    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
  </link>
  <joint name="right_index_pip" type="revolute">
    <origin xyz="0 -0.0014554 0.043" rpy="0 0 0" />
    <parent link="right_index_proximal_link" />
    <child link="right_index_middle_link" />
    <axis xyz="1 0 0" />
    <limit lower="0" upper="1.5708" effort="0" velocity="0" />
  </joint>
  <link name="right_index_distal_link">
    <inertial>
      <origin xyz="3.34671961321059E-07 -0.00120224143694181 0.00777234707760652" rpy="0 0 0" />
      <mass value="0.00183663667769987" />
      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
    </inertial>
    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
  </link>
  <joint name="right_index_dip" type="revolute">
    <origin xyz="0 0 0.022" rpy="0 0 0" />
    <parent link="right_index_middle_link" />
    <child link="right_index_distal_link" />
    <axis xyz="1 0 0" />
    <limit lower="0" upper="1.5708" effort="0" velocity="0" />
  </joint>
  <link name="right_index_tip_link">
    <inertial>
      <origin xyz="2.3798090519056E-08 -0.00705353273135757 -0.0124434081224676" rpy="0 0 0" />
      <mass value="0.000390243409160287" />
      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
    </inertial>
    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
  </link>
  <joint name="right_index_tip" type="fixed">
    <origin xyz="0 0.003512 0.026776" rpy="0 0 0" />
    <parent link="right_index_distal_link" />
    <child link="right_index_tip_link" />
    <axis xyz="0 0 0" />
  </joint>
  <link name="right_middle_proximal_link">
    <inertial>
      <origin xyz="3.04863738940235E-08 -0.00245596411252013 0.0191142544123753" rpy="0 0 0" />
      <mass value="0.0072002618370038" />
      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
    </inertial>
    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
  </link>
  <joint name="right_middle_mcp_flex" type="revolute">
    <origin xyz="0.0075 0 0.106" rpy="0 0 0" />
    <parent link="right_base_link" />
    <child link="right_middle_proximal_link" />
    <axis xyz="1 0 0" />
    <limit lower="0" upper="1.5708" effort="0" velocity="0" />
  </joint>
  <link name="right_middle_middle_link">
    <inertial>
      <origin xyz="-2.85973601964011E-09 -0.000363264332488778 0.00876078146450842" rpy="0 0 0" />
      <mass value="0.00276150069139886" />
      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
    </inertial>
    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
  </link>
  <joint name="right_middle_pip" type="revolute">
    <origin xyz="0 -0.0014554 0.043" rpy="0 0 0" />
    <parent link="right_middle_proximal_link" />
    <child link="right_middle_middle_link" />
    <axis xyz="1 0 0" />
    <limit lower="0" upper="1.5708" effort="0" velocity="0" />
  </joint>
  <link name="right_middle_distal_link">
    <inertial>
      <origin xyz="1.25205983373364E-07 -0.00120223641223895 0.00777324919661349" rpy="0 0 0" />
      <mass value="0.00183690507488675" />
      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
    </inertial>
    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
  </link>
  <joint name="right_middle_dip" type="revolute">
    <origin xyz="0 0 0.022" rpy="0 0 0" />
    <parent link="right_middle_middle_link" />
    <child link="right_middle_distal_link" />
    <axis xyz="1 0 0" />
    <limit lower="0" upper="1.5708" effort="0" velocity="0" />
  </joint>
  <link name="right_middle_tip_link">
    <inertial>
      <origin xyz="-7.96462318148356E-08 -0.00705328274533182 -0.0124432893968912" rpy="0 0 0" />
      <mass value="0.00039026895252879" />
      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
    </inertial>
    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
  </link>
  <joint name="right_middle_tip" type="fixed">
    <origin xyz="0 0.003512 0.026776" rpy="0 0 0" />
    <parent link="right_middle_distal_link" />
    <child link="right_middle_tip_link" />
    <axis xyz="0 0 0" />
  </joint>
  <link name="right_ring_proximal_link">
    <inertial>
      <origin xyz="-2.24219388229863E-08 -0.00245596869794189 0.0191142172606163" rpy="0 0 0" />
      <mass value="0.00720026581090036" />
      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
    </inertial>
    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
  </link>
  <joint name="right_ring_mcp_flex" type="revolute">
    <origin xyz="-0.015626 -0.0011782 0.10542" rpy="0 -0.05236 0.034907" />
    <parent link="right_base_link" />
    <child link="right_ring_proximal_link" />
    <axis xyz="1 0 0" />
    <limit lower="0" upper="1.5708" effort="0" velocity="0" />
  </joint>
  <link name="right_ring_middle_link">
    <inertial>
      <origin xyz="-1.05768104170789E-08 -0.000363267692106015 0.00876078358138278" rpy="0 0 0" />
      <mass value="0.00276150640462905" />
      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
    </inertial>
    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
  </link>
  <joint name="right_ring_pip" type="revolute">
    <origin xyz="0 -0.0014554 0.043" rpy="0 0 0" />
    <parent link="right_ring_proximal_link" />
    <child link="right_ring_middle_link" />
    <axis xyz="1 0 0" />
    <limit lower="0" upper="1.5708" effort="0" velocity="0" />
  </joint>
  <link name="right_ring_distal_link">
    <inertial>
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

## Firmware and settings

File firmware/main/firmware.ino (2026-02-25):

// TetherIA - Open Source Hand
// Aero Hand Firmware Source Code
#include <Arduino.h>
#include <Wire.h>
#include <HLSCL.h>
#include <Preferences.h>
#include "HandConfig.h"
#include "Homing.h"
#include "esp_system.h"

HLSCL hlscl;
Preferences prefs;

// ---- UART pins to the servo bus (ESP32-S3 XIAO: RX=2, TX=3) ----
#define SERIAL2_TX_PIN 3
#define SERIAL2_RX_PIN 2

// ---- Servo IDs (declare at top) ----
const uint8_t SERVO_IDS[7] = { 0, 1, 2, 3, 4, 5, 6 };

ServoData sd[7];

// ---- Constants for Control Code byte ----
static const uint8_t HOMING    = 0x01;
static const uint8_t SET_ID    = 0x02;
static const uint8_t TRIM      = 0x03;
static const uint8_t CTRL_POS  = 0x11;
static const uint8_t CTRL_TOR  = 0x12;
static const uint8_t GET_POS   = 0x22;
static const uint8_t GET_VEL   = 0x23;
static const uint8_t GET_CURR  = 0x24;
static const uint8_t GET_TEMP  = 0x25;
static const uint8_t SET_SPE   = 0x31;
static const uint8_t SET_TOR   = 0x32;

// ---- Defaults for SyncWritePosEx ----
static uint16_t g_speed[7]  = {32766,32766,32766,32766,32766,32766,32766};
static uint8_t  g_accel[7]  = {0,0,0,0,0,0,0};     // 0..255
static uint16_t g_torque[7] = {700,700,700,700,700,700,700}; // 0....1000
static const uint16_t HOLD_MAG = 5;       // the minimal torque actually commanded to the motors during the torque mode. Any torque below that will not be used.

// Last commanded torque per servo (signed)
static int16_t g_lastTorqueCmd[7] = {0};

// ---- Thermal torque limiting (GLOBAL PARAMETERS) ----
static uint8_t  TEMP_CUTOFF_C    = 70;    // °C cutoff
static uint16_t HOT_TORQUE_LIMIT = 500;   // clamp torque when motor exceeds TEMP_CUTOFF_C 

// ----- Registers / constants (Mapped as per Feetech Servo HLS3606M) -----
#define REG_ID                 0x05       // ID register
#define REG_CURRENT_LIMIT      28         // decimal address (word)
#define BROADCAST_ID           0xFE
#define SCAN_MIN               0
#define SCAN_MAX               253
#define REG_BLOCK_LEN          15
#define REG_BLOCK_START        56

// ----- Structure for the Metrics of Servo -------
struct ServoMetrics {
  uint16_t pos[7];
  uint16_t vel[7];
  uint16_t cur[7];
  uint16_t tmp[7];
};
static ServoMetrics gMetrics;

// -------- Global Control Mode State  ---------
enum ControlMode{
  MODE_POS=0,
  MODE_TORQUE=2
};
static ControlMode g_currentMode = MODE_POS;

// ----- Semaphores for Metrics and Bus for acquiring lock and release it -----
static SemaphoreHandle_t gMetricsMux;
SemaphoreHandle_t gBusMux = nullptr;

// ----- Homing module API Calls (provided below as .h/.cpp) --------
bool HOMING_isBusy();
void HOMING_start();

// ---- Helper function to read latest temp from servo
static inline uint8_t getTempC(uint8_t ch) {
  uint8_t t = 0;
  if (gMetricsMux) xSemaphoreTake(gMetricsMux, portMAX_DELAY);
  t = (uint8_t)gMetrics.tmp[ch];
  if (gMetricsMux) xSemaphoreGive(gMetricsMux);
  return t;
}

static inline bool isHot(uint8_t ch) {
  return getTempC(ch) >= TEMP_CUTOFF_C;
}

static inline uint16_t u16_min(uint16_t a, uint16_t b) { return (a < b) ? a : b; }

// ---- Set-ID helpers for setting ID ---
extern void runReIdScanAndSet(uint8_t Id, uint16_t currentLimit);
static volatile int g_lastFoundId; 

// ----- Helper Functions for Set-ID Mode -----
static bool scanRequireSingleServo(uint8_t* outId, uint8_t requestedNewId) {
  uint8_t first = 0xFF;
  int count = 0;
  if (gBusMux) xSemaphoreTake(gBusMux, portMAX_DELAY);
  for (int id = SCAN_MIN; id <= SCAN_MAX; ++id) {
    if (id == BROADCAST_ID) continue;        
    (void)hlscl.Ping((uint8_t)id);
    if (!hlscl.getLastError()) {
      if (count == 0) first = (uint8_t)id;
      ++count;
      if (count > 1) break;                    
    }
  }
  if (gBusMux) xSemaphoreGive(gBusMux);
  if (count == 1) {
    if (outId) *outId = first;
    return true;
  }
  if (count == 0) {
    uint8_t ack6[6] = { 0xFF, 0x00, requestedNewId, 0x00, 0x00, 0x00 };
    sendAckFrame(SET_ID, ack6, sizeof(ack6));
    return false;
  }
  uint8_t ack14[14] = {0xFF, 0xFF, 0xFF, 0xFF, 0xFF, 0xFF, 0xFF, 0xFF, 0x00, 0x00, 0x00, 0x00, 0x00, 0x00};
  sendAckFrame(SET_ID, ack14, sizeof(ack14));
  return false;
}
static void sendSetIdAck(uint8_t oldId, uint8_t newId, uint16_t curLimitWord) {
  uint16_t vals[7] = {0};
  vals[0] = oldId;
  vals[1] = newId;
  vals[2] = curLimitWord;
  uint8_t out[2 + 7*2];
  out[0] = SET_ID;  // 0x03
  out[1] = 0x00;    // filler
  for (int i = 0; i < 7; ++i) {
    out[2 + 2*i + 0] = (uint8_t)(vals[i] & 0xFF);
    out[2 + 2*i + 1] = (uint8_t)((vals[i] >> 8) & 0xFF);
  }
  Serial.write(out, sizeof(out));
}
// ---- Helper function to save and loadManual extends from NVS ------
static void loadManualExtendsFromNVS() {
  prefs.begin("hand", true);  // read-only
  for (uint8_t i = 0; i < 7; ++i) {
    // Store extends per logical channel index, not servo bus ID.
    String key = "ext" + String(i);
    int v = prefs.getInt(key.c_str(), -1);
    if (v >= 0 && v <= 4095) {
      sd[i].extend_count = v;
    }
  }
}

static void saveExtendsToNVS() {
  prefs.begin("hand", false);  // RW
  for (uint8_t i = 0; i < 7; ++i) {
    // Store extends per logical channel index, not servo bus ID.
    String kext = "ext" + String(i);
    prefs.putInt(kext.c_str(), (int)sd[i].extend_count);
  }
  prefs.end();
}

// -------- Soft-Limit Safety for Servo motors
static void checkAndEnforceSoftLimits()
{
  static bool torqueLimited[7] = {false};
  static uint32_t lastCheckMs = 0;
  uint32_t now = millis();
  if (now - lastCheckMs < 20) return;
  lastCheckMs = now;

  if (g_currentMode != MODE_TORQUE) {
    // Only apply soft limits during torque control.
    for (int i = 0; i < 7; ++i) torqueLimited[i] = false;
    return;
  }

  if (gBusMux) xSemaphoreTake(gBusMux, portMAX_DELAY);
  for (uint8_t i = 0; i < 7; ++i) {
    uint8_t id = SERVO_IDS[i];
    int pos = hlscl.ReadPos(id);
    if (pos < 0) pos += 32768;
    uint16_t raw = pos % 4096;
    uint16_t ext = sd[i].extend_count;
    uint16_t gra = sd[i].grasp_count;
    uint16_t rawMin = min(ext, gra);
    uint16_t rawMax = max(ext, gra);
    bool inRange = (raw >= rawMin && raw <= rawMax);
    if (!inRange && !torqueLimited[i]) {
      int16_t limitedTorque = (g_lastTorqueCmd[i] >= 0) ? 200 : -200;
      hlscl.WriteEle(id, limitedTorque);
      torqueLimited[i] = true;
    } else if (inRange && torqueLimited[i]) {
      hlscl.WriteEle(id, g_lastTorqueCmd[i]);
      torqueLimited[i] = false;
    }
  }
  if (gBusMux) xSemaphoreGive(gBusMux);
}


// ---- Helper function  for raw to U16 and U16 to raw ----
static inline uint16_t mapRawToU16(uint8_t ch, uint16_t raw) {
  int32_t ext  = sd[ch].extend_count;
  int32_t gra  = sd[ch].grasp_count;
  int32_t span = gra - ext;
  if (span == 0) return 0;  // avoid divide-by-zero
  int32_t val = ((int32_t)(raw - ext) * 65535L) / span;
  //Clamp
  if (val < 0) val = 0;
  if (val > 65535) val = 65535;
  return (uint16_t)val;
}
static inline uint16_t mapU16ToRaw(uint8_t ch, uint16_t u16) {
  int32_t ext = sd[ch].extend_count;
  int32_t gra = sd[ch].grasp_count;
  int32_t raw32;
  if (ext == 0 && gra == 0) {
    raw32 = ((uint64_t)u16 * 4095u) / 65535u;
  } else {
    raw32 = ext + ((int64_t)u16 * (gra - ext)) / 65535LL;
  }
  // clamp
  if (raw32 < 0)    raw32 = 0;
  if (raw32 > 4095) raw32 = 4095;
  return (uint16_t)raw32;
}

// ---- Helper Functions for u16, Decode to sign and copy values in u16 format----
static inline uint16_t leu_u16(const uint8_t *p) {
  return (uint16_t)p[0] | ((uint16_t)p[1] << 8);
}
static inline int16_t decode_signmag15(uint8_t lo, uint8_t hi) {
  uint16_t mag = ((uint16_t)(hi & 0x7F) << 8) | lo;  // 15-bit magnitude
  return (hi & 0x80) ? -(int16_t)mag : (int16_t)mag;
}
static inline void copy7_u16(uint16_t dst[7], const uint16_t src[7]) {
  for (int i = 0; i < 7; ++i) dst[i] = src[i];
}

// ----- Helper function to send u16 frame for POS,SPD,VEL,CURR and sendACK Packet ----
static inline void sendU16Frame(uint8_t header, const uint16_t data[7]) {
  uint8_t out[2 + 7*2];
  out[0] = header;
  out[1] = 0x00; // filler
  for (int i = 0; i < 7; ++i) {
    out[2 + 2*i + 0] = (uint8_t)(data[i] & 0xFF);
    out[2 + 2*i + 1] = (uint8_t)((data[i] >> 8) & 0xFF);
  }
  Serial.write(out, sizeof(out)); 
}
static inline void sendAckFrame(uint8_t header, const uint8_t* payload, size_t n) {
  uint8_t out[16];
  out[0] = header;
  out[1] = 0x00; // filler
  memset(out + 2, 0, 14);
  if (payload && n) {
    if (n > 14) n = 14;
    memcpy(out + 2, payload, n);
  }
  Serial.write(out, sizeof(out));
}

// ----- Functions to Send POS, VEL, CURR, TEMP -----
void sendPositions() {
  uint16_t buf[7];
  xSemaphoreTake(gMetricsMux, portMAX_DELAY);
  copy7_u16(buf, gMetrics.pos);
  xSemaphoreGive(gMetricsMux);
  sendU16Frame(GET_POS, buf);
}
void sendVelocities() {
  uint16_t buf[7];
  xSemaphoreTake(gMetricsMux, portMAX_DELAY);
  copy7_u16(buf, gMetrics.vel);
  xSemaphoreGive(gMetricsMux);
  sendU16Frame(GET_VEL, buf);
}
void sendCurrents() {
  uint16_t buf[7];
  xSemaphoreTake(gMetricsMux, portMAX_DELAY);
  copy7_u16(buf, gMetrics.cur);
  xSemaphoreGive(gMetricsMux);
  sendU16Frame(GET_CURR, buf);
}
void sendTemps() {
  uint16_t buf[7];
  xSemaphoreTake(gMetricsMux, portMAX_DELAY);
  copy7_u16(buf, gMetrics.tmp);
  xSemaphoreGive(gMetricsMux);
  sendU16Frame(GET_TEMP, buf);
}

// ----- Task - Sync Read running always on Core 1 ----- 
static void TaskSyncRead_Core1(void *arg) {
  uint8_t  rx[REG_BLOCK_LEN];          // 15 bytes
  uint16_t pos[7], vel[7], cur[7], tmp[7];
  const TickType_t period = pdMS_TO_TICKS(10);   // Change Frequency of Running here, 5 -200 Hz, 10-100 Hz, 20 -50 Hz
  TickType_t nextWake = xTaskGetTickCount();
  for (;;) {
    // try-lock: if control is using the bus, skip this cycle
    if (gBusMux && xSemaphoreTake(gBusMux, 0) != pdTRUE) {
      vTaskDelayUntil(&nextWake, period);
      continue;
    }
    bool ok = true;
    // one TX for the whole group (15-byte slice)
    hlscl.syncReadPacketTx((uint8_t*)SERVO_IDS, 7, REG_BLOCK_START, REG_BLOCK_LEN);
    for (uint8_t i = 0; i < 7; ++i) {
      if (!hlscl.syncReadPacketRx(SERVO_IDS[i], rx)) { ok = false; break; }
      uint16_t raw = leu_u16(&rx[0]);
      pos[i] = mapRawToU16(i,raw);                     // Position (unsigned)
      vel[i] = decode_signmag15(rx[2], rx[3]);                  // velocity (signed)
      tmp[i] = rx[7];                                           // temperature (unsigned, 1 byte)
      cur[i] = decode_signmag15(rx[13], rx[14]);                // current (signed)
      //vTaskDelay(1);
    }
    if (gBusMux) xSemaphoreGive(gBusMux);
    if (ok) {
      xSemaphoreTake(gMetricsMux, portMAX_DELAY);
      for (int i = 0; i < 7; ++i) {
        gMetrics.pos[i] = pos[i];
        gMetrics.vel[i] = vel[i];
        gMetrics.tmp[i] = tmp[i];
        gMetrics.cur[i] = cur[i];
      }
      xSemaphoreGive(gMetricsMux);
    } 
    vTaskDelayUntil(&nextWake, period);
  }
}
//Set-ID and Trim Servo functions
static bool handleSetIdCmd(const uint8_t* payload) {
  // Parse request: two u16 words, little-endian
  uint16_t w0 = (uint16_t)payload[0] | ((uint16_t)payload[1] << 8); // newId in low byte
  uint16_t w1 = (uint16_t)payload[2] | ((uint16_t)payload[3] << 8); // requested current limit
  uint8_t  newId    = (uint8_t)(w0 & 0xFF);
  uint16_t reqLimit = (w1 > 1023) ? 1023 : w1;
  // Invalid newId → ACK with oldId=0xFF, newId, cur=0
  if (newId > 253 || newId ==BROADCAST_ID) {
    uint8_t ack[6] = { 0xFF, 0x00, newId, 0x00, 0x00, 0x00 };
    sendAckFrame(SET_ID, ack, sizeof(ack));
    return true;
  }
  // Find any servo present
  uint8_t oldId = 0xFF;
  if (!scanRequireSingleServo(&oldId, newId)) return true; 
  
  if (newId != oldId) {
  if (gBusMux) xSemaphoreTake(gBusMux, portMAX_DELAY);
  (void)hlscl.Ping(newId);
  bool taken = !hlscl.getLastError();
  if (gBusMux) xSemaphoreGive(gBusMux);
  if (taken) {
    uint8_t ack14[14] = { oldId, 0x00, newId, 0x00, 0x00, 0x00, 0x00, 0x00, 0x00, 0x00, 0x00, 0x00, 0x00, 0x00};
    sendAckFrame(SET_ID, ack14, sizeof(ack14));
    return true;
  }
  }
  if (gBusMux) xSemaphoreTake(gBusMux, portMAX_DELAY);
  (void)hlscl.unLockEprom(oldId);
  (void)hlscl.writeWord(oldId, REG_CURRENT_LIMIT, reqLimit);
  uint8_t targetId = oldId;
  if (newId != oldId) {
    (void)hlscl.writeByte(oldId, REG_ID, newId);   // REG_ID = 0x05
    targetId = newId;
  }
  (void)hlscl.LockEprom(targetId);
  
  // Read back limit for ACK
  uint16_t curLimitRead = 0;
  int rd = hlscl.readWord(targetId, REG_CURRENT_LIMIT);
  if (rd >= 0) curLimitRead = (uint16_t)rd;
  if (gBusMux) xSemaphoreGive(gBusMux);
  // Build 6-byte payload: oldId(LE16), newId(LE16), curLimit(LE16) and send
  uint8_t ack[6];
  ack[0] = oldId;                      // oldId lo
  ack[1] = 0x00;                       // oldId hi
  ack[2] = targetId;                   // newId lo
  ack[3] = 0x00;                       // newId hi
  ack[4] = (uint8_t)(curLimitRead & 0xFF);
  ack[5] = (uint8_t)((curLimitRead >> 8) & 0xFF);
  sendAckFrame(SET_ID, ack, sizeof(ack));
  return true;
}
static bool handleTrimCmd(const uint8_t* payload) {
  // Parse little-endian fields
  uint16_t rawCh  = (uint16_t)payload[0] | ((uint16_t)payload[1] << 8);
  uint16_t rawDeg = (uint16_t)payload[2] | ((uint16_t)payload[3] << 8);
  int      ch      = (int)rawCh;         // 0..6
  int16_t  degrees = (int16_t)rawDeg;    // signed degrees
  // Validate channel (0..6)
  if (ch < 0 || ch >= 7) {
    // Optionally send a NACK or silent-accept to preserve framing
    return true;
  }
  // Degrees -> counts (≈11.375 counts/deg), clamp to 0..4095
  int delta_counts = (int)((float)degrees * 11.375f);
  int new_ext = (int)sd[ch].extend_count + delta_counts;
  if (new_ext < 0)    new_ext = 0;
  if (new_ext > 4095) new_ext = 4095;
  sd[ch].extend_count = (uint16_t)new_ext;
  // Persist to NVS
  prefs.begin("hand", false);
  prefs.putInt(String("ext" + String(ch)).c_str(), sd[ch].extend_count);
  prefs.end();
  // ACK payload: ch (u16, LE), extend_count (u16, LE)
  uint8_t ack[4];
  ack[0] = (uint8_t)(ch & 0xFF);
  ack[1] = (uint8_t)((ch >> 8) & 0xFF);
  ack[2] = (uint8_t)(sd[ch].extend_count & 0xFF);
  ack[3] = (uint8_t)((sd[ch].extend_count >> 8) & 0xFF);
  sendAckFrame(TRIM, ack, sizeof(ack));   // 16 bytes on the wire
  return true;
}
static bool handleSetSpeedCmd(const uint8_t* payload)
{
  uint16_t rawId = (uint16_t)payload[0] | ((uint16_t)payload[1] << 8);
  uint16_t rawSpd = (uint16_t)payload[2] | ((uint16_t)payload[3] << 8);
  if (rawId >= 7) {
    //invalid index of servo actuator - So give error code (0–6 valid)
    uint8_t ack[4] = {0xFF, 0xFF, 0x00, 0x00};
    sendAckFrame(SET_SPE, ack, sizeof(ack));
    return true;
  }
  if (rawSpd > 32766) rawSpd = 32766;  // clamp
  g_speed[rawId] = rawSpd;
  // ACK back: servo id and speed
  uint8_t ack[4];
  ack[0] = (uint8_t)(rawId & 0xFF);
  ack[1] = (uint8_t)((rawId >> 8) & 0xFF);
  ack[2] = (uint8_t)(rawSpd & 0xFF);
  ack[3] = (uint8_t)((rawSpd >> 8) & 0xFF);
  sendAckFrame(SET_SPE, ack, sizeof(ack));
  return true;
}
static bool handleSetTorCmd(const uint8_t* payload)
{
  uint16_t rawId = (uint16_t)payload[0] | ((uint16_t)payload[1] << 8);
  uint16_t rawTor = (uint16_t)payload[2] | ((uint16_t)payload[3] << 8);
  // Validate ID range (0..6)
  if (rawId >= 7) {
    uint8_t ack[4] = {0xFF, 0xFF, 0x00, 0x00};  // invalid ID ack
    sendAckFrame(SET_TOR, ack, sizeof(ack));
    return true;
  }
  if (rawTor > 1023) rawTor = 1023;
  // Update the per-servo torque value
  g_torque[rawId] = rawTor;
  uint8_t ack[4];
  ack[0] = (uint8_t)(rawId & 0xFF);
  ack[1] = (uint8_t)((rawId >> 8) & 0xFF);
  ack[2] = (uint8_t)(rawTor & 0xFF);
  ack[3] = (uint8_t)((rawTor >> 8) & 0xFF);
  sendAckFrame(SET_TOR, ack, sizeof(ack));
  return true;
}

// ----- Returns true if a valid 16-byte frame was consumed and handled -----
static bool handleHostFrame(uint8_t op) {
  // Wait until full frame is buffered: filler + 14 payload
  while (Serial.available() < 15) { /* wait */ }
  uint8_t buf[15];
  for (int i = 0; i < 15; ++i) {
    int ch = Serial.read(); if (ch < 0) return false;
    buf[i] = (uint8_t)ch;
  }
  const uint8_t* payload = &buf[1]; // buf[0] = filler 0x00 (ignored)

  switch (op) {
    case CTRL_POS: {
      int16_t pos[7];
      for (int i = 0; i < 7; ++i) {
        uint16_t u16 = (uint16_t)payload[2*i] | ((uint16_t)payload[2*i+1] << 8);
        uint8_t  ch  = i;
        pos[i] = mapU16ToRaw(ch, u16);
      }

      // Torque Servo limit - If motor crosses the TEMP_CUTOFF_C, then keep HOT_TORQUE_LIMIT as the torque
      uint16_t torque_eff[7];
      for (int i = 0; i < 7; ++i) {
        uint16_t base = g_torque[i]; // 0..1023
        if (isHot((uint8_t)i)) {
          base = u16_min(base, HOT_TORQUE_LIMIT);
        }
        torque_eff[i] = base;
      }

      if (gBusMux) xSemaphoreTake(gBusMux, portMAX_DELAY);
      if (g_currentMode != MODE_POS) {
        for (int i = 0; i < 7; ++i) {
          uint8_t id = SERVO_IDS[i];
          hlscl.ServoMode(id);
        }
        g_currentMode = MODE_POS;
      }
      hlscl.SyncWritePosEx((uint8_t*)SERVO_IDS, 7, pos, g_speed, g_accel, torque_eff);
      if (gBusMux) xSemaphoreGive(gBusMux);
      return true;
    }

    case CTRL_TOR: 
    {   
      int16_t torque_cmd[7]; 
      for (int i = 0; i < 7; ++i) 
      {
        uint16_t mag = (uint16_t)payload[2*i] | ((uint16_t)payload[2*i + 1] << 8); 
        if (mag > 1000) mag = 1000; 
        if (mag < HOLD_MAG) mag = HOLD_MAG;
        if (isHot((uint8_t)i)) {
          mag = u16_min(mag, HOT_TORQUE_LIMIT);
        }
        int grasp_sign = (sd[i].extend_count > sd[i].grasp_count) ? +1 : -1;
        torque_cmd[i] = (int16_t)(grasp_sign * (int)mag);
      } 
      for (int i = 0; i < 7; ++i) {
        g_lastTorqueCmd[i] = torque_cmd[i];
      }

      if (gBusMux) xSemaphoreTake(gBusMux, portMAX_DELAY);

      if (g_currentMode != MODE_TORQUE) 
      { 
        for (int i = 0; i < 7; ++i) 
        { 
          uint8_t id = SERVO_IDS[i]; 
          hlscl.EleMode(id); 
        } 
        g_currentMode = MODE_TORQUE;
      } 
      for (int i = 0; i < 7; ++i) 
      { 
        uint8_t id = SERVO_IDS[i]; 
        hlscl.WriteEle(id, torque_cmd[i]); 
      } 
      if (gBusMux) xSemaphoreGive(gBusMux); 
      return true; 
    }

    case SET_TOR: {
      return handleSetTorCmd(payload);
    }

    case SET_SPE: {
      return handleSetSpeedCmd(payload);
    }

    case HOMING: {
      HOMING_start();   // blocks
      saveExtendsToNVS();
      sendAckFrame(HOMING, nullptr, 0);
      return true;
    }

    case SET_ID: {
      return handleSetIdCmd(payload);
    }

    case TRIM: {
      return handleTrimCmd(payload);
    }

    case GET_POS: {
      sendPositions();
      return true;
    }

    case GET_VEL: {
      sendVelocities();
      return true;
    }

    case GET_TEMP: {
      sendTemps();
      return true;
    }

    case GET_CURR: {
      sendCurrents();
      return true;
    }

    default:
      //Unknown Control Code — consume frame to preserve alignment
      return true;
  }
}

void setup() {
  // USB debug
  Serial.begin(921600);
  delay(100);

  // Servo bus UART @ 1 Mbps
  Serial2.begin(1000000, SERIAL_8N1, SERIAL2_RX_PIN, SERIAL2_TX_PIN);
  hlscl.pSerial = &Serial2;

  resetSdToBaseline();
  prefs.begin("hand", false);
  loadManualExtendsFromNVS();
  #if defined(LEFT_HAND)
    Serial.println("[BOOT] Hand Type: LEFT_HAND");
  #elif defined(RIGHT_HAND)
    Serial.println("[BOOT] Hand Type: RIGHT_HAND");
  #else
    Serial.println("[BOOT] Hand Type: UNKNOWN");
  #endif

  esp_reset_reason_t reason = esp_reset_reason();
  bool do_homing = false;
  if (reason == ESP_RST_POWERON) {
    do_homing = true;
  }
  else if (reason == ESP_RST_BROWNOUT) {
    do_homing = true;   // Power-dipped but not fully to 0v , Optional but recommended for safety
  }
  if (do_homing) {
    Serial.println("[BOOT] Power-on detected → homing");
    HOMING_start();
    saveExtendsToNVS();
  } else {
    Serial.println("[BOOT] Non-power reset → skipping homing");
  }

  //Syncreadbegin to Start the syncread
  hlscl.syncReadBegin(sizeof(SERVO_IDS), REG_BLOCK_LEN, /*rx_fix*/ 8);

  //Initialisation of Mutex and Task serial pinned to Core 1
  gBusMux =xSemaphoreCreateMutex();
  gMetricsMux = xSemaphoreCreateMutex();
  xTaskCreatePinnedToCore(TaskSyncRead_Core1, "SyncRead", 4096, NULL, 1, NULL, 1); // run on Core1
}

void loop() {
  static uint32_t last_cmd_ms = 0; 

  // Gate all host input during homing
  if (HOMING_isBusy()) {
    while (Serial.available()) { Serial.read(); }
    vTaskDelay(pdMS_TO_TICKS(5));
    return;
  }

  // ------ Soft Limit Check -------
  checkAndEnforceSoftLimits();

  // Process exactly one complete 16-byte frame when available
  if (Serial.available() >= 16) {
    int op = Serial.read();
    if (op >= 0) {
      if (handleHostFrame((uint8_t)op)) {
        last_cmd_ms = millis();
        return;
      }
    }
  }
}

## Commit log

2025-10-14 Auto-sync/ind2mono-20251013-docs-only (#3)
    * Squashed 'docs/' changes from 1abafa3..bced288
    bced288 User/harsh/firmwaredoc (#13)
    3ee8637 add intro and assemble instruction and sidebar adjustment (#11)
    6b6a7fe shorten title
    8335dd7 find a replicate sentence
    d2932ee rewrite and focus on our hand
    2a55c0e add quick start
    9fb88e4 add hand sim page
    git-subtree-dir: docs
    git-subtree-split: bced2888bff529960f6fd48e08497e4c1eb436f0
    * doc imgs files
    ---------
2025-10-17 add hardware readme file (#10)
    * add hardware readme file
    * 15 joints -> 16 joints
    * fix physical material
    * cable -> tendon
    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
2025-10-17 git subrepo clone --branch=public_release https://github.com/TetherIA/aero-open-ros2.git ros2 (#11)
    subrepo:
    subdir: "ros2"
    merged: "8c87f05"
    upstream:
    origin: "https://github.com/TetherIA/aero-open-ros2.git"
    branch: "public_release"
    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
    [aero_hand_open_right.urdf, right_base_link.STL, right_index_distal_link.STL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]
2025-10-29 Revise README with new sections and links (#19)
    Updated the README to include new sections on mechanical, assembly, hardware setup, PCB, and firmware, along with relevant links.
2025-11-12 git subrepo commit (merge) hardware
    subdir: "hardware"
    merged: "ec9e8ea"
    origin: "https://github.com/TetherIA/aero-open-hardware.git"
    branch: "main"
    commit: "43ab47d"
    git-subrepo:
    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
    [BOM.csv]
2025-11-12 DELETE: old hardware files
    [100ufcap.stp, 22-03-5035.step, 22057035.step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]
2025-11-12 FIX: spell fix in CSV
    [BOM.csv]
2026-02-09 Firmware v0.1.4 (#41)
    * update release note for firmware
    * Fix subrepo parent pointer
    * git subrepo pull --branch=main firmware
    subdir: "firmware"
    merged: "5eff4fb"
    origin: "https://github.com/TetherIA/aero-open-firmware.git"
    commit: "5eff4fb"
    version: "0.4.9"
    origin: "https://github.com/ingydotnet/git-subrepo"
    commit: "6232cc5"
    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
    [firmware.ino]
2026-02-25 update firmware 0.1.5 (#42)
    * Fix subrepo parent commit after rebase
    merged: "d5c1533"
    commit: "d5c1533"
    origin: "https://github.com/Homebrew/brew"
    commit: "490e51d47f"
    * update release note
    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
    [firmware.ino]
2026-02-26 Auto sync/ind2mono 20260225 (#43)
    * UPDATE: parent commit
    merged: "b2222cb"
    commit: "b2222cb"
    origin: "https://github.com/ingydotnet/git-subrepo.git"
    commit: "8bbc88c"
    * UPDATE: parent commits
    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
    [aero_hand_open_left.urdf]
2026-03-13 add G1_Open_Unitree_Converter for unitree g1 (#44)
    add G1_Open_Unitree_Converter for unitree g1
    [G1_Open_Unitree_Converter.stp]

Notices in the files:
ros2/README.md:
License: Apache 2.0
